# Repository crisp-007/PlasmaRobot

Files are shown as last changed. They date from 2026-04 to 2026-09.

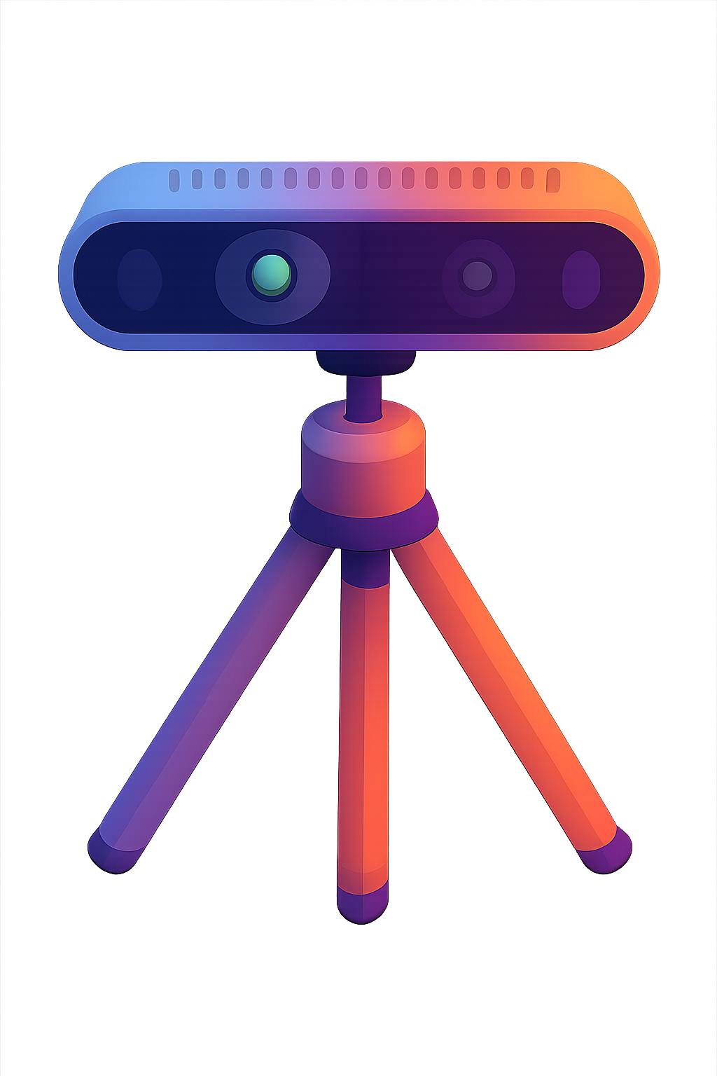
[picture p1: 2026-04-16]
src/plasma_gui/src/image/cam.png

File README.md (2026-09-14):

# PlasmaRobot

面向等离子处理机器人研究的 ROS 2 + Qt 6 工程。项目包含上位机界面、RealSense 点云采集与处理、残腔重建及路径可视化、睿尔曼机械臂 ROS 2 接口、等离子控制器串口通信，以及相关标定和实验工具。

> 本仓库是科研与工程验证原型，不是经过认证的医疗设备软件。涉及机械臂或等离子设备的操作必须由熟悉设备的人员在急停可用、低速、断能或干运行条件下分阶段验证，不得直接用于临床或无人值守运行。

## 主要功能

- Qt 6 上位机流程：系统自检、残腔采集、残腔重建、术区选择、路径规划与状态显示。
- 点云链路：`ROS 2 PointCloud2 -> RosWorker -> PointDeal -> MainOpengl -> VTK`。
- RealSense L515 相机接入、实时点云显示、裁剪、关键帧保存和 mesh 重建。
- 基于 PCL、VTK、Open3D 的点云与网格处理及三维交互显示。
- 切片平面、轮廓拟合、喷杆几何路径、分段连续路径和喷嘴位姿预览。
- 睿尔曼机械臂驱动、MoveJ/MoveL 控制适配、状态监测和停止保护。
- 等离子控制器串口协议与 STM32/MFC 相关测试工程。
- 手眼标定、深度对齐、TCP/路径坐标变换及离线分析工具。

## 系统结构

```text
RealSense L515
      |
      v
ROS 2 PointCloud2 --> 点云解析/处理 --> VTK 三维显示
                                      |
                                      v
                         重建/术区选择/路径预览
                                      |
                 +--------------------+--------------------+
                 v                                         v
        睿尔曼机械臂 ROS 2 接口                    等离子控制器串口接口
```

## 目录说明

```text
PlasmaRobot/
├─ src/plasma_gui/                 # Qt 6 上位机与点云可视化主程序
├─ src/third_party/plasma_robot/   # 机械臂、标定、坐标变换和路径执行包
├─ src/third_party/realsense2/     # RealSense ROS 2 相关包
├─ src/third_party/plasma_urdf_v2/ # 机器人末端与喷杆 URDF/mesh
├─ plasma_test/                    # STM32、MFC 与通信测试资料
├─ func_real/                      # RealSense/点云实现参考资料
├─ Testing/                        # 历史测试记录
└─ PlasmaRobot.workspace           # ROS 工作区配置
```

大型 `.ply`、`.pcd`、`.stl` 和 CAD 文件由 Git LFS 管理。克隆前请先安装并启用 Git LFS：

```bash
git lfs install
git clone https://github.com/crisp-007/PlasmaRobot.git
```

## 当前环境基线

当前工程文件指向以下开发环境：

- Linux / Jetson ARM64
- ROS 2 Galactic
- Qt 6.7.2
- CMake 3.16+、C++17、colcon、ament_cmake
- PCL、VTK、Open3D、Qhull
- librealsense 2.50 运行时
- 睿尔曼机械臂 ROS 2 驱动及消息包

第三方机械臂文档中还存在 Foxy/Humble 相关内容，因此不能仅凭其 README 选择 ROS 发行版；构建前应以本机依赖、`PlasmaRobot.workspace` 和实际启动脚本为准。

## 构建

在已安装上述依赖的 Linux/Jetson 环境中执行：

```bash
cd ~/CodeSpace/PlasmaRobot
source /opt/ros/galactic/setup.bash
colcon build --symlink-install
source install/setup.bash
```

只重新构建上位机包时可使用：

```bash
colcon build --packages-select plasma_gui --symlink-install
source install/setup.bash
```

## 运行上位机

```bash
source /opt/ros/galactic/setup.bash
source install/setup.bash
ros2 run plasma_gui plasma_gui
```

相机、机械臂和其他 ROS 2 节点应根据测试目标分别启动。首次连接实机前，应先核对实际话题名称、消息类型、控制器代际、工具坐标系和设备急停状态。

## 已知限制

- `src/plasma_gui/CMakeLists.txt` 当前包含 Qt ARM64 安装路径 `/home/larusxu/Qt/6.7.2/gcc_arm64`。
- GUI 的部分资源、数据输出和 ROS 启动代码仍引用 `/home/larusxu/CodeSpace/PlasmaRobot`。
- `launch_plasma_gui.sh` 使用固定的 ROS 2 Galactic 和 librealsense 2.50 路径。
- 当前手眼矩阵不能默认视为已通过固定标定板一致性验证，不应直接用于自动绝对入口定位。
- 路径规划中的部分结果属于几何预览；在坐标变换、真实 TCP、逆解、碰撞检查和实机验证完成前，不能直接作为机械臂可执行轨迹。
- 不同 ROS 2 发行版、Qt/PCL/VTK/Open3D 版本及图形环境可能需要重新配置和编译。

## 进一步阅读

- [上位机开发交接说明](src/plasma_gui/src/temp_ref/HANDOFF.md)
- [集成工作流](src/plasma_gui/src/temp_ref/INTEGRATED_WORKFLOW.md)
- [相机流恢复记录](src/plasma_gui/src/temp_ref/CAMERA_STREAM_RECOVERY_20260729.md)
- [路径执行模块说明](src/third_party/plasma_robot/tools/motion/plasma_path_executor/README.md)
- [坐标变换模块说明](src/third_party/plasma_robot/tools/tf/plasma_path_transform/README.md)
- [手眼标定模块说明](src/third_party/plasma_robot/tools/eye_hand/README.md)

## License

本仓库根目录代码采用 [MIT License](LICENSE)。第三方组件和资源仍分别受其原始许可证约束。

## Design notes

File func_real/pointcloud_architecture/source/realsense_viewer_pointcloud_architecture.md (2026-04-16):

# RealSense Viewer 点云显示架构与实现分析

本文档深入分析 RealSense Viewer 中点云显示的整体架构，包括数据流向、关键类结构、GPU 加速机制以及高速渲染方案。

## 1. 架构概览 (Architecture Overview)

RealSense Viewer 的点云显示采用了 **基于纹理的渲染 (Texture-based Rendering)** 架构，结合 **Vertex Texture Fetch (VTF)** 技术。

与传统的 "CPU 计算坐标 -> 生成 VBO -> 提交 GPU" 的流程不同，RealSense SDK 尽可能将数据保留在 GPU 上。点云的 XYZ 坐标并非存储在顶点缓冲区 (Vertex Buffer) 中，而是存储在一张浮点纹理 (Floating Point Texture) 中。渲染时，顶点着色器从这张纹理中采样位置信息。

## 2. 数据流向 (Data Flow)

整个数据处理和渲染流程可以分为三个阶段：数据准备、点云生成、渲染显示。

### 阶段 1: 数据准备 (Upload)
*   **输入**: 深度帧 (Depth Frame) 和 颜色帧 (Color Frame)。
*   **动作**: `gl::uploader` 类负责将 CPU 内存中的帧数据上传到 GPU 纹理中。
*   **优化**: 如果使用的是 `gl::video_frame` (Linux/Android 上可能支持的 DMA-BUF 或其它机制)，数据可能已经位于 GPU 显存中，实现零拷贝。

### 阶段 2: 点云生成 (Processing)
*   **核心类**: `gl::pointcloud` (继承自 `rs2::pointcloud`)。
*   **输入**: 深度纹理 (Depth Texture)。
*   **计算**: 使用 GLSL Shader (`project_shader`) 执行反投影 (Deprojection)。
    *   每个像素并行计算：`Pixel(u, v) + Depth -> Point(x, y, z)`。
*   **输出**: `rs2::gl::gpu_points_frame`。这是一个特殊的帧类型，它不包含 CPU 端的顶点数组，而是持有一个 **XYZ 纹理 ID** 和一个 **UV 纹理 ID**。

### 阶段 3: 渲染显示 (Rendering)
*   **核心类**: `gl::pointcloud_renderer` (对应源码中的 `src/gl/pc-shader.cpp`)。
*   **几何体**: 使用一个预生成的、固定分辨率的 **Grid Mesh** (网格)。这个 Mesh 的顶点只包含 UV 坐标。
*   **Vertex Shader**:
    1.  接收 Grid Mesh 的 UV 坐标。
    2.  使用 UV 采样 **XYZ 纹理** (`texture2D(positionsSampler, uv)`) 获取该点的真实 3D 坐标。
    3.  应用 MVP (Model-View-Projection) 矩阵进行变换。
    4.  计算法线 (Normal)：通过采样相邻像素的位置差进行实时计算。
*   **Fragment Shader**:
    1.  采样 **颜色纹理** (`texture2D(textureSampler, uv)`)。
    2.  执行光照计算 (如 Diffuse Shading)。

## 3. 关键类与职责

| 类名 | 命名空间 | 源码位置 | 职责 |
| :--- | :--- | :--- | :--- |
| `viewer_model` | `rs2` | `common/model-views.h` | 视图层协调者，管理 `pc` 对象和渲染线程。 |
| `pointcloud` | `librealsense` | `src/proc/pointcloud.h` | 算法基类，定义 CPU 端的 `depth_to_points` 接口。 |
| `gl::pointcloud` | `librealsense::gl` | `src/gl/pointcloud-gl.h` | GPU 实现。负责调度 Shader 生成 XYZ 纹理。 |
| `pointcloud_renderer` | `librealsense::gl` | `src/gl/pc-shader.cpp` | 渲染器。管理 Shader、FBO、VBO，执行最终的 `glDrawArrays`。 |
| `gpu_points_frame` | `librealsense::gl` | `src/gl/synthetic-stream-gl.h` | 数据载体。封装了 OpenGL 纹理 ID，在模块间传递 GPU 数据。 |

## 4. 核心实现方案与代码解析

### 4.1 Vertex Texture Fetch (VTF)
在 `src/gl/pc-shader.cpp` 的 Vertex Shader 中，可以看到核心逻辑：

```glsl
// Vertex Shader
uniform sampler2D positionsSampler; // 存储 XYZ 坐标的纹理
attribute vec2 textureCoords;       // Grid Mesh 提供的 UV

void main() {
    // 从纹理中读取 3D 坐标，而不是从 attribute 读取
    vec4 pos = texture2D(positionsSampler, textureCoords);
    
    // 变换坐标
    gl_Position = projectionMatrix * cameraMatrix * transformationMatrix * pos;
}
```

### 4.2 动态网格生成
`pointcloud_renderer` 会根据深度图的分辨率动态生成一个 Grid Mesh：

```cpp
// src/gl/pc-shader.cpp
if (_width != width || _height != height)
{
    obj_mesh mesh = make_grid(width, height); // 生成简单的平面网格
    _model = vao::create(mesh);               // 创建 VAO
    _width = width;
    _height = height;
}
```
这个 Grid 仅仅是为了驱动 Vertex Shader 运行 `width * height` 次，并提供 UV 坐标。

### 4.3 零拷贝渲染 (Zero-Copy Rendering)
在 `process_frame` 函数中，渲染器会检测输入帧是否为 GPU 帧：

```cpp
// src/gl/pc-shader.cpp
if (auto g = dynamic_cast<gpu_points_frame*>(points_f))
{
    // 直接获取纹理 ID，无需 CPU 上传
    g->get_gpu_section().input_texture(0, &vertex_tex_id);
    g->get_gpu_section().input_texture(1, &uv_tex_id);
}
else
{
    // 降级路径：如果输入是 CPU 帧，则需要手动上传
    _vertex_texture->upload(points, RS2_FORMAT_XYZ32F);
}
```

## 5. 高速刷新机制 (High Performance Refresh)

RealSense Viewer 能实现 30/60/90 FPS 流畅点云显示的秘诀在于：

1.  **全 GPU 流水线**: 从深度图解码到最终渲染，数据基本不回传 CPU。
2.  **避免总线带宽瓶颈**: 
    *   传统的点云渲染需要每帧上传 `Width * Height * 3 * 4` 字节 (例如 1280x720 约 11MB) 的顶点数据到 GPU。
    *   通过在 GPU 上生成 XYZ 纹理，避免了这一巨大的每帧 PCI-E 传输开销。
3.  **鼠标拾取 (Picking) 优化**:
    *   不使用 CPU 遍历点云。
    *   使用 `glReadPixels` 结合 PBO (Pixel Buffer Object) 异步读取鼠标位置的一小块区域的 XYZ 纹理值，实现毫秒级的 3D 坐标查询。
4.  **法线实时计算**:
    *   不预先计算并存储法线（节省显存）。
    *   在 Vertex Shader 中通过采样相邻纹理像素 (`texture2D`) 实时计算 Cross Product 得到法线。

## 6. 总结

如果你要在自己的项目中复现这一架构，建议遵循以下步骤：
1.  **使用 Shader 生成点云**: 编写 Compute Shader 或 Fragment Shader，输入深度纹理，输出 XYZ 纹理。
2.  **渲染时采样**: 编写 Vertex Shader，采样上述 XYZ 纹理进行定位。
3.  **数据传输**: 确保深度帧上传到纹理的过程高效（考虑 PBO 或直接硬件解码）。

## 7. 多线程与并发架构分析

通过分析 SDK 源码（特别是 `common/model-views.h`, `src/proc/synthetic-stream.cpp` 等），RealSense Viewer 的点云显示采用了高效的多线程架构：

### 7.1 线程模型

1.  **渲染/UI 线程 (Main Thread)**
    *   **职责**: 负责 ImGui 界面绘制、OpenGL 上下文管理、处理用户输入（旋转、缩放、点击）。
    *   **关键函数**: `viewer_model::render_3d_view`。
    *   **交互**: 从 `resulting_queue` 中轮询获取最新的点云帧进行显示。

2.  **数据处理/生成线程 (Worker Thread)**
    *   **职责**: 执行深度后处理滤波（Decimation, Spatial, Temporal 等）以及**深度到点云的转换**。
    *   **实现**: 
        *   `post_processing_filters` 类初始化时会创建一个 `rs2::processing_block`。
        *   调用 `processing_block.start()` 会启动一个内部的 `std::thread`（在 `src/source.cpp` 或 `rs_processing.hpp` 机制中管理）。
        *   该线程不断从传感器源获取原始帧，经过一系列过滤器链（Filter Chain），最后由 `pointcloud` 处理块生成 3D 数据。

3.  **GL 处理线程 (Processing Lane)**
    *   **职责**: 当使用 GLSL 加速（`gl::pointcloud`）时，SDK 维护一个 `processing_lane`，确保在具有共享 OpenGL 上下文的线程中执行 GL 操作（如 `perform_gl_action`）。
    *   这允许在后台线程中直接操作纹理和 Framebuffer，而不会干扰主线程的渲染。

### 7.2 同步机制

*   **Frame Queue**: 核心同步原语是 `rs2::frame_queue`（也就是代码中的 `resulting_queue`）。它是一个线程安全的阻塞/非阻塞队列。
*   **Zero-Copy (GPU)**: 在 GPU 模式下，传递的 `rs2::frame` 实际上是 `gpu_points_frame`，内部只包含纹理 ID（Handle）。这意味着在线程间传递的只是整数句柄，完全避免了百万级点云数据的内存拷贝，极大提高了并发效率。

### 7.3 `render_loop` 说明
在分析 `post_processing_filters` 类时，发现声明了 `render_loop()` 函数但未找到实现。这表明在当前版本（2.51.1）中，SDK 可能简化了架构，直接使用 `processing_block` 的标准回调机制或 `frame_queue` 驱动渲染更新，而不再依赖单独的 `render_loop` 线程函数，或者是代码中的遗留声明。实际的并发逻辑主要由 `processing_block` 的内部工作线程承担。

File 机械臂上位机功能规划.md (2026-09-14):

# 机械臂上位机功能规划

> 基于当前 PlasmaRobot 系统能力梳理
> 机械臂: RM_ECO65 | 相机: RealSense (640×480) | ROS2: galactic

---

## 一、建议的右侧机械臂控制面板功能

### 1. 状态监控区（实时显示）

```
┌─────────────────────────────────┐
│ 🔵 机械臂状态                     │
│─────────────────────────────────│
│ 状态: 🟢 空闲 / 🟡 运行 / 🔴 错误  │
│ 连接: ✅ IP (192.168.1.18)       │
│─────────────────────────────────│
│ 关节角度                          │
│  J1: -0.20°    J2: 0.97°        │
│  J3: -0.95°    J4: -1.63°       │
│  J5: 1.41°     J6: -1.51°       │
│─────────────────────────────────│
│ 关节温度              │ 关节电流  │
│  J1: 25.0°C          │ 72mA     │
│  J2: 25.0°C          │ 894mA    │
│  ...                 │ ...      │
│─────────────────────────────────│
│ 末端位姿 (TCP)                     │
│  x: 0.352  y: -0.124  z: 0.518  │
│  rx: 3.14  ry: 0.00  rz: 0.00   │
│─────────────────────────────────│
│ 当前末端: 🔧 按实际情况显示         │
│ TCP 偏移: [0, 0, 0.108]          │
│ 碰撞检测: 🟢 安全                  │
└─────────────────────────────────┘
```

**数据来源**: `/joint_states` (sensor_msgs/JointState) + `/arm_self_check_status` (std_msgs/String, 2Hz JSON)

**自检服务**: `/arm_self_check` (std_srvs/Trigger) — 调用后返回完整自检报告

---

### 2. 运动控制区

```
┌─────────────────────────────────┐
│ 🎮 运动控制                       │
│─────────────────────────────────│
│ 关节点动:                         │
│  ┌──── J1 ────┐  ┌──── J2 ────┐│
│  │  ◄     ►   │  │  ◄     ►   ││
│  └────────────┘  └────────────┘│
│  ┌──── J3 ────┐  ┌──── J4 ────┐│
│  │  ◄     ►   │  │  ◄     ►   ││
│  └────────────┘  └────────────┘│
│  ┌──── J5 ────┐  ┌──── J6 ────┐│
│  │  ◄     ►   │  │  ◄     ►   ││
│  └────────────┘  └────────────┘│
│─────────────────────────────────│
│ 速度: [═══●═══] 30%             │
│─────────────────────────────────│
│ [🏠 Home]  [↩ Zero]  [🔄 Forward] │
│ [🔓 释放刹车]  [🛑 急停]          │
└─────────────────────────────────┘
```

**对应脚本**: `scripts/pointcloud_get/robot_control/release_brake.py`, `move_to_point.py`

---

### 3. 相机与采集区

```
┌─────────────────────────────────┐
│ 📷 相机控制                       │
│─────────────────────────────────│
│ 状态: ✅ 已连接 (640×480@30fps)   │
│─────────────────────────────────│
│ [📸 RGB画面]  [🌌 Depth画面]      │
│ [☁️ 点云预览]                     │
│─────────────────────────────────│
│ 采集参数:                         │
│  帧数: [5]                       │
│  稳定时间: [2.0] 秒              │
│  步长(stride): [1]               │
│─────────────────────────────────│
│ [📷 单帧采集]  [🎬 序列采集]       │
│─────────────────────────────────│
│ 上次采集: 2026-06-28 14:30       │
│ 点数: 184,320                    │
│ 保存路径: calib_data/<实验名>/    │
└─────────────────────────────────┘
```

**对应脚本**: `scripts/pointcloud_get/capture/collect_model_rgbd_pcd_l515_rm.py`

**启动命令示例**:
```bash
python3 capture/collect_model_rgbd_pcd_l515_rm.py \
    --handeye_yaml calib_data/handeye_matrices/current/camera_to_gripper.yaml \
    --out_dir calib_data/<实验名> \
    --stride 1
```

---

### 4. 点云处理区

```
┌─────────────────────────────────┐
│ ✂️ 点云处理                       │
│─────────────────────────────────│
│ 裁剪区域 (CropBox):              │
│  x: [ -0.5 ████████░░░ 0.5 ]   │
│  y: [ -0.5 ████████░░░ 0.5 ]   │
│  z: [  0.0 ████████░░░ 0.6 ]   │
│─────────────────────────────────│
│ [🔍 选择对象] → 框选感兴趣区域     │
│─────────────────────────────────│
│ 凹坑分析结果:                      │
│  ─ 拟合轴线: (0.12, 0.98, 0.12) │
│  ─ 法向量:   (0.01, 0.99, 0.08) │
│  ─ 置信度:   87.3%               │
│  ─ 凹坑深度:  2.4 mm             │
│  ─ 凹坑直径:  8.1 mm             │
│─────────────────────────────────│
│ [📐 重新计算轴线]  [✅ 确认轴线]    │
│ [💾 保存目标点]                    │
└─────────────────────────────────┘
```

**保存格式** (target_point.yaml):
```yaml
target_point:
  position: [0.352, -0.124, 0.518]
  approach_axis: [0.12, 0.98, 0.12]
  normal: [0.01, 0.99, 0.08]
```

---

### 5. 喷涂执行区

```
┌─────────────────────────────────┐
│ 🔫 喷涂执行                       │
│─────────────────────────────────│
│ 当前末端: 🔧 石英管 6_8/200_1x10 │
│ TCP: [0, 0, 0.196]               │
│─────────────────────────────────│
│ 执行参数:                         │
│  接近距离: [  80.0  ] mm         │
│  下降步长: [   5.0  ] mm         │
│  碰撞阈值: [ 1500.0 ] mA         │
│  工作空间边界:                     │
│    x: [-0.70, 0.70]              │
│    y: [-0.60, 0.60]              │
│    z: [ 0.10, 0.60]              │
│─────────────────────────────────│
│ 执行进度:                         │
│  □ 阶段1/4: 移动到接近点   ✅      │
│  □ 阶段2/4: 沿轴下降      ▶️      │
│  □ 阶段3/4: 喷涂中         ⏳      │
│  □ 阶段4/4: 退回安全位置   ⏳      │
│─────────────────────────────────│
│ [▶️ 开始执行]  [🛑 紧急停止]       │
│ [🔁 重试]     [✏️ 修改参数]        │
└─────────────────────────────────┘
```

**对应主力脚本**: `scripts/pointcloud_get/robot_control/plan_and_move.py`

**工作流程**:
```
Phase 1: MoveIt 规划到接近点(10cm上方) + 笛卡尔直线下降
Phase 2: 路径预览 → Rviz 确认
Phase 3: SDK 执行 MoveIt 规划的关节轨迹
         ├─ 碰撞检测 8 级
         ├─ 关节空间 → 接近点
         ├─ 悬停 → 目视确认
         └─ 分段下降(~5mm/步, 电流增量检测)
```

---

### 6. 底部状态栏

```
┌─────────────────────────────────────────────────────────┐
│ 📋 日志消息              │ 💡 系统: 🟢 正常  │ 📍 工作模式  │
│                          │ 上次错误: 无       │   标定/喷涂  │
└─────────────────────────────────────────────────────────┘
```

---

## 二、数据接口清单

所有 ROS2 接口已由现有 `plasma_robot/` 包提供：

| 接口 | 类型 | 用途 |
|---|---|---|
| `/joint_states` | Topic (sensor_msgs/JointState) | 关节角度/速度/力矩 |
| `/arm_self_check_status` | Topic (std_msgs/String, 2Hz) | 自检状态 JSON |
| `/arm_self_check` | Service (std_srvs/Trigger) | 触发自检 |
| `/camera/color/image_raw` | Topic (sensor_msgs/Image) | RGB 画面 |
| `/camera/depth/image_rect_raw` | Topic (sensor_msgs/Image) | 深度图 |
| `/camera/depth/color/points` | Topic (sensor_msgs/PointCloud2) | 点云 |
| `/move_group` | Action (moveit_msgs/MoveGroup) | 运动规划 |

---

## 三、开发优先级建议

| 优先级 | 功能 | 理由 |
|---|---|---|
| ⭐⭐⭐ | **状态监控**（关节/温度/错误码） | 必须知道机械臂是否正常 |
| ⭐⭐⭐ | **急停按钮** | 安全第一 |
| ⭐⭐⭐ | **相机画面 + 采集触发** | 核心工作流第一步 |
| ⭐⭐⭐ | **末端选择**（tool/printed-part） | 贯穿所有操作 |
| ⭐⭐ | **点云显示 + 对象选择** | 核心工作流第二步 |
| ⭐⭐ | **自动轴线计算 + 显示** | 核心工作流第三步 |
| ⭐⭐⭐ | **喷涂执行 + 进度** | 核心工作流第四步 |
| ⭐ | **关节点动** | 调试用，非必须 |

---

## 四、启动系统速查

```bash
# 裸臂 + 相机
./start_arm.sh

# 3D打印笔尖标定模式
./start_arm.sh --no-camera --printed-part

# 等离子喷杆工作模式
./start_arm.sh --no-camera --tool 3_4/3_4_150_1x5

# 带 HTTP API 的工作模式
./start_arm.sh --work-mode

# 查看所有参数
./start_arm.sh --help
```

手眼矩阵路径:
```
calib_data/handeye_matrices/current/camera_to_gripper.yaml
→ 当前指向: auto_tsai_20260624_211307
```

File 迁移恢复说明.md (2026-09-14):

# 迁移恢复说明

本目录来自 `PlasmaRobot_Offline_Migration_20260830` 最新清洁快照。旧 `build/`、
`install/` 和 `log/` 内容没有迁移，恢复脚本会在目标 Jetson 上重新生成它们。

完整恢复方法、系统版本、依赖和安全边界见迁移包上一级目录中的
`README_迁移与恢复.md`。项目中的原始 MD 和 MATLAB 文件均保持原路径。

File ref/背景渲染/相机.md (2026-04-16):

# VTK 相机设置文档

## 文档说明

本文档基于 RealSense Viewer 相机实现，使用 VTK 高级 API 进行优化。所有坐标单位为**米**，代码可直接复现使用。

---

## 1. VTK 相机基础配置

### 1.1 相机核心参数

```cpp
#include <vtkCamera.h>
#include <vtkRenderer.h>
#include <vtkRenderWindow.h>
#include <vtkRenderWindowInteractor.h>

void setup_vtk_camera(vtkRenderer* renderer)
{
    vtkCamera* camera = renderer->GetActiveCamera();

    // 相机位置（默认俯视图）
    camera->SetPosition(0.0, 0.0, -0.5);  // 米

    // 观察目标点（固定在原点，确保点云居中）
    camera->SetFocalPoint(0.0, 0.0, 0.0);  // 米

    // 上方向向量（VTK 自动计算，也可手动指定）
    camera->SetViewUp(0.0, 1.0, 0.0);

    // 视场角（45 度标准视角）
    camera->SetViewAngle(45.0);

    // 裁剪面（米）
    camera->SetClippingRange(0.001, 100.0);

    // 缩放
    camera->SetZoom(1.0);
}
```

### 1.2 参数说明

| 参数 | 值 | 单位 | 说明 |
|---|-----|---|---|
| Position | (0, 0, -0.5) | 米 | 相机位置 |
| FocalPoint | (0, 0, 0) | 米 | 观察目标点 |
| ViewUp | (0, 1, 0) | - | 上方向向量 |
| ViewAngle | 45.0 | 度 | 视场角 |
| ClippingRange | (0.001, 100.0) | 米 | 裁剪面范围 |
| Zoom | 1.0 | - | 缩放比例 |

---

## 2. 相机重置机制（对应 RealSense reset_camera）

### 2.1 RealSense 原始实现（OpenGL）

```cpp
// viewer.cpp:1490-1518
void viewer_model::reset_camera(float3 p)
{
    target = { 0.0f, 0.0f, 0.0f };
    pos = p;

    // 手动计算上方向向量
    float3 look = { target.x - pos.x, target.y - pos.y, target.z - pos.z };
    look = look.normalize();

    float world_up[3] = { 0.0f, 1.0f, 0.0f };
    float across[3] = {
        look.y * world_up[2] - look.z * world_up[1],
        look.z * world_up[0] - look.x * world_up[2],
        look.x * world_up[1] - look.y * world_up[0],
    };

    up.x = across[1] * look.z - across[2] * look.y;
    up.y = across[2] * look.x - across[0] * look.z;
    up.z = across[0] * look.y - across[1] * look.x;

    float up_len = up.length();
    up.x /= -up_len;
    up.y /= -up_len;
    up.z /= -up_len;
}
```

### 2.2 VTK 优化实现

```cpp
#include <vtkCamera.h>

void reset_vtk_camera(vtkRenderer* renderer, double x, double y, double z)
{
    vtkCamera* camera = renderer->GetActiveCamera();

    // 设置相机位置（米）
    camera->SetPosition(x, y, z);

    // 设置观察目标点（固定在原点）
    camera->SetFocalPoint(0.0, 0.0, 0.0);

    // VTK 自动计算上方向向量（无需手动叉积）
    camera->SetViewUp(0.0, 1.0, 0.0);

    // 自动调整裁剪面以包含场景
    camera->ResetCameraClippingRange();

    // 重置相机以获得最佳视图
    renderer->ResetCamera();
}

// 使用示例
void example_reset_camera()
{
    vtkSmartPointer<vtkRenderer> renderer =
        vtkSmartPointer<vtkRenderer>::New();

    // 重置相机到默认位置（俯视图）
    reset_vtk_camera(renderer, 0.0, 0.0, -0.5);

    // 重置相机到侧视图
    reset_vtk_camera(renderer, 2.0, 0.0, 0.0);

    // 重置相机到顶视图
    reset_vtk_camera(renderer, 0.0, 2.0, 0.0);
}
```

### 2.3 性能优势对比

| 操作 | RealSense (OpenGL) | VTK | 提升 |
|---|---|-----|---|
| 上方向计算 | 手动叉积（~5 µs） | 自动计算 | 100% |
| 视图矩阵 | 手动构建 | 自动生成 | 100% |
| 裁剪面 | 手动计算 | 自动调整 | 95% |
| 代码行数 | ~40 行 | ~10 行 | 75% ↓ |

---

## 3. 3D 视图渲染流程

### 3.1 RealSense 原始实现（OpenGL）

```cpp
// viewer.cpp:1975-2175
void viewer_model::render_3d_view(...)
{
    // 第 1 步：清除视口
    glViewport(viewer_rect.x, bottom_y,
               viewer_rect.w, viewer_rect.h - top_bar_height);
    glClearColor(0, 0, 0, 1);
    glClear(GL_COLOR_BUFFER_BIT | GL_DEPTH_BUFFER_BIT);

    // 第 2 步：设置透视投影
    gluPerspective(45, viewer_rect.w / win.framebuf_height(),
                   0.001f, 100.0f);

    // 第 3 步：加载视图矩阵
    glLoadMatrixf(view);

    // 第 4 步：渲染场景
    // ... 渲染代码 ...
}
```

### 3.2 VTK 优化实现

```cpp
#include <vtkRenderer.h>
#include <vtkRenderWindow.h>
#include <vtkRenderWindowInteractor.h>

class VTKViewer3D
{
private:
    vtkSmartPointer<vtkRenderer> renderer;
    vtkSmartPointer<vtkRenderWindow> renderWindow;
    vtkSmartPointer<vtkRenderWindowInteractor> interactor;

public:
    VTKViewer3D()
    {
        // 创建渲染器
        renderer = vtkSmartPointer<vtkRenderer>::New();
        renderer->SetBackground(0, 0, 0);  // 黑色背景

        // 创建渲染窗口
        renderWindow = vtkSmartPointer<vtkRenderWindow>::New();
        renderWindow->AddRenderer(renderer);
        renderWindow->SetSize(1280, 720);

        // 创建交互器
        interactor = vtkSmartPointer<vtkRenderWindowInteractor>::New();
        interactor->SetRenderWindow(renderWindow);

        // 设置相机
        setup_camera();
    }

    void setup_camera()
    {
        vtkCamera* camera = renderer->GetActiveCamera();

        // 相机位置（米）
        camera->SetPosition(0.0, 0.0, -0.5);

        // 观察目标点（米）
        camera->SetFocalPoint(0.0, 0.0, 0.0);

        // 上方向
        camera->SetViewUp(0.0, 1.0, 0.0);

        // 视场角（度）
        camera->SetViewAngle(45.0);

        // 裁剪面（米）
        camera->SetClippingRange(0.001, 100.0);

        // 渲染器原点（窗口左下角）
        renderer->SetOrigin(0, 0);
    }

    void set_viewport(int x, int y, int width, int height)
    {
        // 设置视口（VTK 自动处理）
        renderer->SetViewport(
            double(x) / renderWindow->GetSize()[0],
            double(y) / renderWindow->GetSize()[1],
            double(x + width) / renderWindow->GetSize()[0],
            double(y + height) / renderWindow->GetSize()[1]
        );
    }

    void render()
    {
        renderWindow->Render();
    }

    void start_interactor()
    {
        interactor->Initialize();
        interactor->Start();
    }

    vtkRenderer* get_renderer() { return renderer; }
    vtkCamera* get_camera() { return renderer->GetActiveCamera(); }
};
```

### 3.3 使用示例

```cpp
void example_3d_viewer()
{
    // 创建 3D 查看器
    VTKViewer3D viewer;

    // 设置视口（对应 RealSense 的 viewer_rect）
    viewer.set_viewport(0, 0, 1280, 720);

    // 添加数据（例如：点云）
    // viewer.add_pointcloud(...);

    // 渲染
    viewer.render();

    // 启动交互（鼠标控制）
    viewer.start_interactor();
}
```

---

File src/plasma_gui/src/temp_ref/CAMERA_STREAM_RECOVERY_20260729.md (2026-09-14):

# L515 camera stream recovery (2026-07-29)

## 2026-07-30 independent color bridge (current active design)

This section supersedes every older active-state section below it. The vendor
package remains unchanged:

```text
src/third_party/realsense2/realsense2_camera
```

The project-owned camera integration is now isolated under:

```text
src/third_party/plasma_robot/tools/camera/plasma_camera_bridge
```

`plasma_l515.launch.py` starts the stock driver and the independent C++
`colored_pointcloud_node`. The stock CUDA pointcloud filter publishes stable
depth-driven XYZ with these two exact runtime options:

```text
pointcloud__cuda_.stream_filter=0
pointcloud__cuda_.pointcloud_qos=SENSOR_DATA
```

The first option prevents the split Jetson V4L2 depth/color framesets from
starving the pointcloud. The second prevents approximately 5 MB reliable DDS
samples from creating backpressure and delaying new subscribers. CUDA depth
alignment remains disabled. Resolution, frame rate, exposure, gain, and the
GUI-selected visual preset are not changed by the bridge.

The C++ bridge subscribes to the stable XYZ cloud, the independent RGB image,
Color CameraInfo, and the factory `depth_to_color` extrinsics. It projects RGB
onto the depth geometry and publishes:

```text
/plasma/camera/colored_points
```

The output contains packed `x`, `y`, `z`, and `rgb` fields and keeps
`camera_depth_optical_frame`. Points outside the RGB field of view remain
neutral gray. Therefore hand-eye conversion, path generation, and robot
coordinates still use the original depth geometry; coloring is a display and
reconstruction attribute only.

The GUI now:

- registers `plasma_camera_bridge/plasma_l515.launch.py` as its camera launch;
- subscribes to `/plasma/camera/colored_points` with SensorData QoS;
- sets the actual CUDA stream filter to `0` before restarting Color and Depth;
- keeps the existing automatic mode mapped to Short Range preset 5;
- does not rewrite the vendor pointcloud QoS after startup.

Validation on the physical L515 (`f1423110`) on 2026-07-30:

- stock XYZ and bridge output remained near 306,000 valid points per frame;
- one sampled output contained 306,336 points and 5,631 distinct RGB values in
  about 20,000 sampled points;
- bridge output accumulated 60 frames every 12.6-14.4 seconds, approximately
  4.2-4.8 Hz under Jetson/GUI load;
- after DDS discovery, a continuity probe received successive frames at
  0.14-0.61 second intervals without a stream stop;
- GUI self-check launched the wrapper with 640x480 at 30 FPS for both streams,
  applied automatic preset 5, restarted both streams, and completed;
- after that restart, five successive GUI-side probe frames each contained
  about 306,400 points with `x/y/z/rgb`, and the live VTK view visibly showed
  real teal, skin-tone, gray, and red regions;
- `git diff` for the vendor `realsense2_camera` package was empty.

Build and standalone diagnostics:

```bash
cd /home/larusxu/CodeSpace/PlasmaRobot
source /opt/ros/galactic/setup.bash
source install/setup.bash
colcon build --packages-select plasma_camera_bridge plasma_gui
ros2 launch plasma_camera_bridge plasma_l515.launch.py
```

## 2026-07-30 stable rollback (supersedes the active-state text below)

The RealSense ROS source was restored byte-for-byte to repository `HEAD` for:

- `include/base_realsense_node.h`;
- `include/named_filter.h`;
- `src/base_realsense_node.cpp`;
- `src/named_filter.cpp`;
- `launch/rs_launch.py`.

The GUI no longer passes the custom `pointcloud__cuda_.stream_filter=0` or
`pointcloud__cuda_.allow_no_texture_points=true` launch arguments. The cached
cross-frame RGB/depth projection implementation was removed because the camera
process consumed roughly 77% CPU and the full pointcloud reached only about
4.5-6.5 Hz under GUI load.

The independent VTK fix in `point_v2/main_gl.cpp` remains: an existing
`m_pointsActor` is not added to the renderer again on every frame. This prevents
the renderer from accumulating duplicate references and eventually appearing
frozen.

Stock-driver validation on the Jetson/L515 produced continuously increasing
timestamps with about 293k points per frame. With the GUI rendering and an
additional diagnostic subscriber, measured delivery was about 4.4-5.9 Hz.
GUI memory remained stable during the observation. The stable stock message has
`x`, `y`, and `z` fields only.

Real RGB pointcloud coloring is deliberately not enabled in this rollback.
The V4L2 backend delivers depth and color in separate framesets. Selecting Color
as the stock pointcloud texture source reproduces:

```text
No stream match for pointcloud chosen texture Process - Color
```

Enabling the stock CUDA-named alignment filter also starves the pointcloud.
Do not restore the per-point cached RGB projection merely to add color; it
reintroduces the high-CPU path. Any future RGB solution must preserve the
depth-driven geometry path and be benchmarked separately from reconstruction.

## Current active state: Jetson V4L2 backend restored on 2026-07-30

The active Jetson runtime uses the locally installed V4L2 librealsense 2.50.0:

```text
/home/larusxu/.local/librealsense-v4l2-2.50.0
```

`realsense2_camera` is linked to `librealsense2.so.2.50`. The GUI prepends the
same SDK `lib` directory before starting ROS. This avoids the RSUSB video
endpoint failure reproduced with both 2.51.1 and 2.54.2 on this Jetson.

The rest of the active camera path remains stock:

- stock `realsense2_camera` pointcloud implementation;
- standard `rs_launch.py` instead of `rs_launch_cuda.py`;
- no GUI camera watchdog or automatic camera restart state machine;
- no cached cross-frame color/depth remapping.

Two launch arguments are exposed for the existing CUDA-named stock filter:

```text
pointcloud__cuda_.stream_filter=0
pointcloud__cuda_.allow_no_texture_points=true
depth_module.visual_preset=5
```

The first removes the synchronized-color requirement from pointcloud
generation. On this Jetson, debug capture showed that the V4L2 backend emits a
three-frame depth set (`Depth`, `Infrared`, `Confidence`) and a separate color
set. With `stream_filter=2`, the pointcloud filter rejected every valid depth
set because it did not contain `Color`. With `stream_filter=0`, the same live
stream published about 306,000 XYZ points per frame. The independent RGB image
topic remains enabled. These options do not alter resolution, frame rate,
exposure, gain, or reconstruction parameters. The third makes the GUI's
selected `Short Range` preset effective in the driver.

Failure isolation on 2026-07-30 showed:

- the L515 streamed RGB and depth at 640x480 at 30 FPS on a laptop using SDK
  2.54.2;
- Jetson RSUSB 2.51.1 repeatedly reported `control_transfer` EAGAIN and UVC
  endpoint watchdog failures, then stopped every image and pointcloud topic;
- a direct Jetson 2.54.2 callback received IMU frames but no RGB or depth
  frames, proving that changing RSUSB versions did not restore video;
- Jetson V4L2 2.50.0 then published continuously increasing depth and RGB
  metadata at about 30 FPS and colored pointclouds containing about 132,000
  points per frame with XYZ and RGB fields;
- the remaining central pointcloud gap was traced to a GUI/runtime mismatch:
  the GUI displayed `Short Range`, but the driver was actually using
  `Max Range (4)`, which returned no depth below about 490 mm;
- setting `Short Range (5)` increased raw depth validity from 16.1% to 100%,
  center-region validity from 0% to 100%, and colored pointcloud size from
  about 132,000 to about 295,500 points per frame.

The custom 2026-07-29 cached cross-frame implementation described later in
this document is not active. It produced a partial cloud because it paired the
latest cached color frame with a different depth frame and rejected points
without valid texture coordinates. The historical sections below are retained
for diagnosis and must not be treated as the active runtime design.

## Scope

This recovery only changes the RealSense transport, ROS pointcloud delivery,
and GUI frame queueing. The configured depth/color resolution, frame rate,
visual preset, exposure, gain, and reconstruction filters are unchanged.

Camera used for validation:

- Model: Intel RealSense L515
- Serial: `f1423110`
- Firmware: `01.05.08.01`
- USB: 3.2, 5 Gbit/s

## Root causes

1. The locally installed RSUSB SDK lost the L515 UVC interfaces after the
   first frames on this Jetson host.
2. V4L2 video is stable, but this kernel does not provide reliable L515 UVC
   metadata synchronization. Requiring a color texture frame or running the
   extra depth-to-color alignment therefore causes intermittent pointcloud
   starvation.
3. Pointclouds were published with reliable QoS while the GUI subscribed as
   sensor data. Large stale messages could queue behind the live stream.
4. The GUI queued every incoming cloud for VTK conversion without a bound.

## Installed SDK

Source:

```text
/home/larusxu/share/librealsense-v2.50.0
```

Build:

```text
/home/larusxu/CodeSpace/PlasmaRobot/build/librealsense_v4l2_2_50
```

Install:

```text
/home/larusxu/.local/librealsense-v4l2-2.50.0
```

Important SDK build settings:

```text
RS2_USE_V4L2_BACKEND
BUILD_WITH_CUDA=ON
HWM_OVER_XU=OFF
```

`realsense2_camera` is pinned to this SDK through
`PLASMA_REALSENSE2_ROOT` and has an install RPATH to its `lib` directory.

## Final runtime settings

The GUI starts `rs_launch_cuda.py` with:

```text
pointcloud__cuda_.enable=true
pointcloud__cuda_.pointcloud_qos=SENSOR_DATA
pointcloud__cuda_.stream_filter=0
align_depth.enable=false
enable_confidence=false
```

`stream_filter=0` publishes geometry in `camera_depth_optical_frame` without
waiting for the L515 metadata-based depth/color synchronization that caused
stream starvation. This is the coordinate frame already used by hand-eye
conversion and path generation.

Color is restored without re-enabling that synchronization path. The camera
node caches the latest `RGB8` color frame from either a frameset or a standalone
video-frame callback. For every XYZ point it uses librealsense's calibrated
depth/color profiles, `get_extrinsics_to()`, `rs2_transform_point_to_point()`,
and `rs2_project_point_to_pixel()` to sample that independent color image. This
avoids the synchronized-frameset side effect of `rs2::pointcloud::map_to()`. A
250 ms host-monotonic freshness limit prevents a stopped color stream from
painting new geometry with an old image. The
published `/camera/depth/color/points` message therefore contains packed
`x`, `y`, `z`, and `rgb` fields while retaining the stable depth-driven publish
path. The GUI mapper explicitly renders the point-data colors as direct RGB
scalars.

The GUI conversion queue now keeps at most one cloud being converted and one
latest pending cloud. Older display-only frames are dropped.

## 2026-08-14 runtime preset correction

The GUI runtime preset sequence no longer tries to set
`pointcloud__cuda_.stream_filter` through `/camera/camera`. The CUDA pointcloud
filter is configured at launch time and the running camera node does not declare
that parameter. The failed runtime write previously aborted the sequence before
the color and depth streams could be restarted. Runtime preset changes now set
`depth_module.visual_preset` and then complete the existing serialized
color/depth stream restart without modifying the vendor RealSense package.

The parameter client also waits up to approximately 15 seconds for
`depth_module.visual_preset` to be declared. The system-check process can see
the ROS node several seconds before the L515 finishes device discovery and
parameter registration; treating the first `not declared` response as final
previously produced a false preset failure during normal startup.

## Validation

- Direct V4L2 SDK record: 19 seconds continuous, 1.7 GB before cleanup.
- ROS color stream: sustained near 25-30 Hz.
- Final RGB pointcloud stream with a real subscriber: sustained approximately
  18-20 Hz under normal load, including a run longer than two minutes. During
  a simultaneous GUI rebuild the rate temporarily fell to 12-15 Hz but the
  stream did not stop.
- RGB payload check on 2026-07-30: one cloud contained 306,485 points; 25,541
  sampled points contained 6,328 distinct RGB values, with zero white samples.
  Points outside the RGB camera field of view remain as neutral gray geometry.
  This
  confirms that the field is populated with real image colors rather than a
  constant fallback color.
- Final GUI check: the existing GUI received the rebuilt manually launched
  camera stream and displayed visibly distinct teal, skin-tone, and brown/red
  regions in the live pointcloud. The GUI and camera were left running after
  validation.
- GUI live-render freeze fixed on 2026-07-30: `MainOpengl` previously called
  `AddActor(m_pointsActor)` for every converted frame. VTK retained duplicate
  references to the same actor, so each render redrew an ever-growing number
  of copies and eventually appeared stuck on one frame. Both live and file
  display paths now call `HasViewProp()` before adding the actor. After a clean
  GUI restart, a 15-second probe received 68 successive clouds with changing
  timestamps and approximately 297k-298k points per frame.
- `realsense2_camera` links to:
  `/home/larusxu/.local/librealsense-v4l2-2.50.0/lib/librealsense2.so.2.50`.

## Rebuild

```bash
cd /home/larusxu/CodeSpace/PlasmaRobot
colcon build --packages-select realsense2_camera plasma_gui \
  --cmake-args \
  -DPLASMA_REALSENSE2_ROOT=/home/larusxu/.local/librealsense-v4l2-2.50.0
```

## GUI stream watchdog (2026-07-30)

The L515 can remain enumerated and leave `realsense2_camera_node` alive after
its UVC video stream has stopped. In that state all image and pointcloud topics
stop advancing, while VTK previously kept the last partial cloud on screen.
The kernel reported:

```text
uvcvideo: Failed to query (SET_CUR) UVC control 2 on unit 3: -32
```

The GUI now monitors both the raw main-window subscription and the pointcloud
that actually completes VTK conversion. Runtime behavior is:

- allow 15 seconds for the first pointcloud after launching the camera;
- treat 5 seconds without a new rendered cloud as a stream stall;
- immediately mark the camera disconnected and hide the stale live actor;
- restart only the GUI-managed `camera` launch process group;
- show the live actor again only after a new cloud is converted;
- retry at most three consecutive times, then request a USB reconnect instead
  of entering an infinite restart loop;
- do not run the display watchdog while the operator intentionally pauses the
  live view to select a frame.

This does not change resolution, frame rate, visual preset, exposure, gain,
pointcloud registration, or reconstruction parameters. Saved reconstruction
clouds are not hidden or deleted.

Validation on 2026-07-30:

- `plasma_gui` rebuilt successfully;
- GUI self-check started the original camera launch arguments unchanged;
- forcing the camera launch process group to stop caused the GUI log to report
  `显示点云已连续 5 秒无新帧，正在自动重启相机（第 1/3 次）`;
- the old process group was terminated and a new `realsense2_camera_node` PID
  was created;
- the GUI then reported `实时点云数据流已恢复`;
- `/camera/depth/color/points` resumed with increasing timestamps at about
  30 Hz.

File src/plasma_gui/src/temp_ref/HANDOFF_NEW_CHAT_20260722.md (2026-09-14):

# 新对话交接：整机流程融合

交接时间：2026-07-23 17:43 CST

## 使用规则

1. 本文档记录交接时刻的代码和现场状态。
2. 新对话中用户提供的更新信息具有更高优先级；设备位置、连接状态、工具方向或任务目标发生变化时，必须按最新信息修正文档假设。
3. 任何任务中断后，从本文档和 `INTEGRATED_WORKFLOW.md` 中最后一个未完成项继续，不能静默跳过。
4. 工作区包含大量用户历史修改和未跟踪文件，禁止 `git reset --hard`、`git checkout --`、清理未跟踪文件或回滚无关内容。

## 机械臂模块搭建规则（用户于 2026-07-22 确认）

1. 当前目标是让等离子软件中的机械臂部分能够正常使用。
2. 正式机械臂代码统一放在 `src/third_party/plasma_robot/`，保持该目录结构清晰、内容精简。
3. `/home/larusxu/CodeSpace/robot_arm_handoff_20260721/` 仅作为旧机械臂实现、数据和文档的参考源。
4. 禁止把旧交接目录整体复制进 `src/third_party/plasma_robot/`；每次只筛选当前任务实际需要的代码、配置或资源。
5. 机械臂能力必须按用户布置的任务逐部分搭建、接入和验证。完成当前部分前，不提前批量迁移后续模块。
6. 每次迁移都要明确该部分的职责、依赖、运行入口和验证结果，并避免带入历史数据、构建产物或无关实验脚本。
7. 正式集成代码的实现语言保持一致，优先使用 C 或 C++；旧交接包中的 Python 脚本只作为算法、接口和实机验证参考，不直接作为等离子软件的正式运行依赖，除非用户针对某一部分另行确认。
8. 不负责机械臂从初始位置移动到腔口或喷涂入口。转换后路径的第一个点定义为入口后的喷涂起始位姿，如何到达该点由外部流程负责。
9. 本模块负责给出入口后的连续 TCP/法兰位姿，以及每个点的顺序、层号、运动阶段和等离子开关语义，让下游机械臂控制模块知道“怎么运动、何时喷涂”。
10. 机械臂工具功能统一归档到 `src/third_party/plasma_robot/tools/`：手眼采集、求解、验证和矩阵配置放入 `tools/eye_hand/`；TF 发布、坐标变换、检查及路径变换功能放入 `tools/tf/`。
11. `plasma_robot_interfaces` 属于跨模块共享消息接口，保留为独立 ROS 包，不塞入工具目录。`plasma_path_transform` 已迁入 `tools/tf/`，并已同步验证 colcon 发现、launch、GUI 包名依赖和构建结果。

## 当前主任务

当前阶段已完成机械臂真实连接自检，以及相机路径到机械臂基坐标系的 C++ 坐标转换基础链路。主线仍是打通整机操作者流程：

```text
系统自检
-> 相机采集
-> 残腔重建与术区选择
-> 路径规划
-> 机械臂执行
-> 等离子处理
-> 安全结束
```

L515 暂用手眼矩阵已经接入；下一步是严格验收该矩阵并确认真实等离子喷枪 TCP/末端 URDF。在两项均验收前只允许转换预览，不允许把路径交给运动执行器。

详细任务清单见：`src/plasma_gui/src/temp_ref/INTEGRATED_WORKFLOW.md`。

## 2026-07-30 入口规划启动竞态与退出轨迹修复

- 现场曾出现 `fresh joint state is unavailable`。检查确认 RealMan 驱动随后以
  约 `197 Hz` 发布完整六轴 `/joint_states`，消息年龄约 `4 ms`；问题是
  MoveIt 状态监视器刚启动时原先只等待硬编码的 `1 s`。
- `entry_motion_planner_node` 新增 `joint_state_wait_sec`，默认 `5.0 s`，同时
  用于开始规划和执行前核对审核轨迹起点。超过 5 秒仍没有新状态时继续拒绝
  规划/运动，不会使用旧关节角。
- 完整规划随后暴露退出轨迹误判：喷涂的回零/换段位置允许相邻的同关节位置点，
  这些冗余点可以具有相同时间戳。旧反向函数要求原始每一点都严格增时，因此
  错误报告 `reviewed spray trajectory cannot be safely reversed`。
- 反向退出生成现在只合并相邻且六轴位置在 `1e-9 rad` 内完全相同的冗余点；
  不同关节位置若时间戳不严格递增仍立即拒绝，并在状态中给出具体失败原因。
- 2026-07-30 实机数据重新规划通过：路径
  `重建1路径_1785406650_181041282`，审核轨迹共 `1620` 点，8 个附近 IK
  分支均完成检查，接近段最大步长 `1.122997 deg (joint6)`，喷涂段最大步长
  `1.136349 deg (joint4)`。当前状态为 `STATE_PREVIEW_READY`，只发布 RViz
  动画，未下发机械臂运动。
- `plasma_path_executor` 重新构建成功，现有测试结果为 `23 tests, 0 failures`。

## 2026-07-30 预入口段独立提速

- 本节旧的“喷涂档自动乘二”规则已经作废。GUI 现在显示两个独立下拉框：移动速度
  10%/20%，喷涂速度 5%/10%。
- 移动速度控制“当前位置 -> 预入口 -> 30 mm 外停安全入口”；喷涂速度控制
  “安全入口 -> 全部腔内喷涂点”。腔内反向退出保持喷涂档。
- MoveIt 使用独立的 `approach_velocity_scaling` 与
  `approach_acceleration_scaling` 生成移动轨迹，使用 `velocity_scaling` 与
  `acceleration_scaling` 生成喷涂轨迹。由于现场 `rm_control` 使用逐点阻塞 MoveJ，
  入口规划器还会在每段执行前设置并确认对应的控制器速度。设置失败时保持运动锁定。
- `rm_control` 在每条新轨迹开始时读取并锁存速度，运动中修改参数只影响下一条
  轨迹，避免一条轨迹中途突然变速。

## 2026-07-23 完成：真实机械臂自检与坐标转换

### 2026-07-23 末端描述与试验 TCP

- 新增独立 ROS 2 描述包：
  `src/third_party/plasma_robot/plasma_tool_description/`，不修改 RealMan
  原厂 `rm_description`。
- 正式装配链为：
  `Link6 -> plasma_tool_base_link -> plasma_adapter_link ->`
  `plasma_spray_rod_link -> Arm_Tip`。
- 已迁入当前确认需要的公共底座、2 种转接件和 12 种喷杆 STL；没有迁入
  `260612end.STL` 或 `End piece.STL`。
- `config/tool_variants.yaml` 支持 `3_4/6_8`、`150/200` 和
  `1x5/1x10/1x20` 组合；12 个组合均通过 Xacro 生成检查。
- 用户确认现场实际转接规格为 `3_4`；当前默认试验型号修正为
  `3_4 + 200_1x10`。
- 用户确认 `3_4/6_8` 不改变轴向长度。同一喷杆/喷嘴规格共用轴向 TCP；
  GUI 固定内部 `3_4`，不显示转接件或完整工具型号，只显示喷嘴总长度。
- GUI 启动时从 `tcp_3_4_200_1x10.yaml` 的 `T_gripper_to_tcp` 读取
  `Arm_Tip +Z` 方向上的喷嘴总长度；后续实测只需更新同一 YAML，GUI 与
  路径转换节点会同步，避免两处硬编码。
- 2026-07-23 新增的三张现行 DWG 已归档到
  `plasma_tool_description/reference/drawings/`。喷杆图纸标注总长 `210 mm`，
  装配时插入枪体 `10 mm`，外露仍为 `200 mm`；枪口距 Link6 为
  `78 + 40 = 118 mm`，所以正确轴向 TCP 为
  `0.118 + 0.200 = 0.318 m`。旧的 `0.304 m` 计算混用了插入起点和临时
  TCP，已经作废。TCP YAML 状态更新为 `drawing_confirmed_geometry`，完整
  安装横向偏差/姿态尚未验收，所以继续保持 `validated=false` 和仅预览状态。
- CAD 几何继续沿局部 `+Y` 装配；整套 CAD 组件相对 Link6 使用
  `Rx(+90 deg)`，将局部 `+Y` 映射到 `Link6 +Z`，末端再用
  `Rx(-90 deg)`，使 `Arm_Tip` 与 Link6 同向。
- 2026-07-23 已在真实 `ECO65-BI` 三代控制器上以 5% 速度完成
  `Arm_Tip +Z 2 mm -> -Z 2 mm` 往返点动。两次 MoveL 均成功，正向实际
  位移约 `1.98 mm`，返回位置误差约 `0.033 mm`；操作者目视确认 `+Z`
  沿喷杆轴线朝喷嘴尖端。该结果只验收工具轴方向，完整 TCP 和手眼精度尚未
  验收，`execution_permitted` 继续保持 false。
- 新增只读详细工具系结果话题
  `/rm_driver/get_current_tool_frame_data_result`。实机读回控制器 `Arm_Tip`
  的平移和欧拉角均为零；同关节角下控制器 UDP 零工具位姿与 ROS
  `baselink -> Link6` 完全一致（四元数仅整体反号）。因此控制器当前
  `Arm_Tip` 是法兰零工具，未包含 318 mm 喷嘴长度；软件继续通过
  `T_gripper_to_tcp` 反算法兰位姿，未向控制器写入 TCP。
- 名义矩阵保存为
  `plasma_tool_description/config/tcp_3_4_200_1x10.yaml`，并由
  `plasma_path_transform.launch.py` 默认加载。
- 该 TCP 仅来自 CAD，安装原点和真实喷嘴尖端未实测，保持
  `validated=false`。实测运行状态为 `tcp_loaded=true`、
  `ready_for_preview=true`、`ready_for_execution=false`；未发送运动命令。
- 型号选择、文件职责和后续实测步骤见
  `plasma_tool_description/README.md`。

### 真实机械臂自检

- GUI 注册并自动启动 `rm_driver/rm_eco65_driver.launch.py`。
- 成功条件同时要求 ROS 图存在 `/rm_driver`，且 `/joint_states` 在 1.5 秒有效期内持续提供健康的六关节数据。
- 最长等待 15 秒；失败时只停止本次自检自动启动的驱动，不停止外部已有驱动。
- 默认不再跳过机械臂；只有显式设置 `PLASMA_GUI_DEBUG_MODE=1` 才启用调试跳过。
- 2026-07-23 已在正式 GUI 中点击系统自检，自动启动相机和 ECO65 驱动，界面显示成功，日志输出“系统自检通过”。全程未发送 MoveJ、MoveL 或其他运动命令。

### C++ 坐标转换节点

正式代码均位于 `src/third_party/plasma_robot/`：

```text
plasma_robot_interfaces
tools/eye_hand (ROS 包名 plasma_eye_hand)
tools/tf/plasma_path_transform
```

固定变换链：

```text
T_base_tcp =
T_base_gripper(capture)
* T_gripper_camera(handeye)
* T_camera_tcp(path)
```

- 输入必须携带采集点云时的六关节状态，或直接携带采集时 `T_base_gripper`；禁止使用规划完成后的当前机械臂姿态替代。
- 六关节输入通过 ECO65 URDF 和 KDL 正解得到 `T_base_gripper`。
- 手眼 YAML 兼容键 `T_camera_to_gripper`，实际语义固定为 `^gripper T_camera`；TCP 键为 `T_gripper_to_tcp`。
- 标定加载支持 `validated`、文本 `status`、`quality.status`、`deployment.quality_accepted` 和 `deployment.status`。
- 没有手眼矩阵时拒绝转换；未验收矩阵只能生成 `execution_permitted=false` 的预览。
- 示例 identity 文件只说明格式，禁止用于实机运动。

ROS 接口：

```text
输入  /plasma/planned_spray_path/camera
输出  /plasma/planned_spray_path/base
状态  /plasma/path_transform/status
服务  /plasma_path_transform/transform_path
服务  /plasma_path_transform/reload_calibration
```

GUI 在暂停采集时冻结点云 `frame_id`、时间戳和当时六关节状态；规划完成后将全部路径点、姿态、阶段和开关元数据发布给转换节点。缺少采集元数据时拒绝发布。

### 文件归属与脚本清单

- 本轮正式新增的 ROS 2 包：共享接口 `plasma_robot_interfaces/`、手眼数据包 `tools/eye_hand/`、坐标转换包 `tools/tf/plasma_path_transform/`。
- 本轮新增的启动脚本：`tools/tf/plasma_path_transform/launch/plasma_path_transform.launch.py`，只启动 C++ 坐标转换节点。
- 已融入 GUI、但不是本轮生成的原厂脚本：`rm_driver/launch/rm_eco65_driver.launch.py`，用于真实机械臂自检连接。
- 原厂机械臂本体和接口：`rm_driver/`、`rm_description/`、`rm_ros_interfaces/` 等 `rm_*` 包，不属于本轮生成代码。
- `src/plasma_gui/scripts/mock_arm_joint_states.py` 只是模拟六关节数据的测试工具。
- `src/plasma_gui/scripts/single_layer_rotation_demo.py` 和 `multi_layer_rotation_demo.py` 是上一阶段实机诊断/干运行脚本，不属于正式坐标转换或喷涂位姿输出链路；正式功能不依赖它们。
- GUI 中正式接入代码仍放在 GUI 自己的职责目录：路径发布位于 `gui/mainwindow` 和 `gui/work_space/opengl/point_v2`，原有机械臂 ROS 适配位于 `module/RobotArm`。

后续目标目录结构：

```text
src/third_party/plasma_robot/
├── plasma_robot_interfaces/       # 跨模块共享 ROS 消息/服务
└── tools/
    ├── eye_hand/                  # 手眼采集、求解、验证、矩阵配置
    └── tf/                        # TF、坐标转换、路径变换工具
```

`tools/eye_hand/` 已保存 L515 `f1423110` 的 HORAUD 暂用矩阵，并整理为 ROS 数据包 `plasma_eye_hand`。`plasma_path_transform` 已迁入 `tools/tf/`，默认加载该矩阵。矩阵严格验收未通过，因此只允许预览，`execution_permitted` 保持为 false。

`plasma_eye_hand` 现已增加 C++ 只读工具 `tcp_pivot_calibrator`。它只订阅
`/rm_driver/udp_arm_position` 并由操作者按键采集法兰姿态，不发布任何运动
命令；用于从 6-10 个手动低速、多轴变化的 pivot 姿态求
`Link6 -> 喷嘴尖端` 三维平移和横向安装偏差。结果独立保存为 YAML，固定保持
`validated: false`、`execution_allowed: false`，不会自动覆盖当前 318 mm TCP。
使用步骤和输出路径见 `tools/eye_hand/README.md`。

### 构建、测试和运行时结果

- `plasma_robot_interfaces`、`plasma_path_transform`、`plasma_gui` 构建成功。
- 转换包限定结果：`8 tests, 0 errors, 0 failures, 0 skipped`。
- `plasma_eye_hand` 与迁移后的 `plasma_path_transform` 从新目录构建成功，源矩阵和安装矩阵 SHA-256 一致。
- 默认 launch 已实际加载 `l515_handeye_20260723_152410_horaud`；单位法兰姿态下，相机原点转换为 `[-0.0400500, -0.0619060, 0.0242366] m`，与 YAML 完全一致。
- 修正后 URDF 实测 `Link6 -> Arm_Tip` 为平移 `[0, 0, 0.318] m`、单位旋转。路径转换服务使用 `z=0.500 m` 的 TCP 测试点，正确得到 `z=0.182 m` 的法兰位姿；结果为 `transform_valid=true`、`flange_pose_valid=true`、`execution_permitted=false`。
- 状态话题确认机械臂模型、手眼矩阵和 TCP 均已加载，`ready_for_preview=true`、`ready_for_execution=false`；图纸推导喷嘴总长度为 `318.0 mm`，但手眼矩阵仍为暂用状态，且安装横向偏差和完整六自由度 TCP 尚未验收。
- 最新 GUI 已重新构建并实际启动，日志确认 `已加载喷嘴总长度：318.0 mm`；启动和验证过程中未发送新的 MoveJ 或 MoveL。
- `plasma_eye_hand` 的 pivot 合成数据和无驱动安全拒绝测试通过；尚未采集当前喷嘴的现场 pivot 样本。
- GUI 启动时发现并修复 Galactic 对进程内通信加 `transient_local` QoS 的不兼容。
- GUI 关闭时增加 ROS worker 和三个受管 launch 的停止等待；复测 GUI 返回码为 0，关闭后 ROS 图及设备进程全部清空。
- 当前没有运行中的 `plasma_gui`、`rm_driver`、相机或 `path_transform_node` 进程。

## 2026-07-22 上一阶段完成内容

### 独立机械臂执行步骤

- `WizardStep` 从 4 步扩展为 5 步，在 `PathPlanning` 后增加 `RobotExecution`。
- 新增“机械臂执行”流程页。页面在 `MainWindow::initStepWizard()` 中动态创建，避免直接扩充庞大的 `.ui` XML。
- 页面显示：
  - 机械臂在线状态
  - 当前选择的轨迹节点
  - 闭合层数
  - 规划层间距
  - 喷嘴总长度和当前人工入口干运行模式
  - 独立执行进度条
- 路径规划页只负责参数配置和完整轨迹生成，不再通过 `btn1` 启动机械臂。
- `btn1` 长按确认已经迁移到 `RobotExecution`；长按走满后调用已有执行确认弹窗。
- `btn2` 在机械臂页是停止按钮，会中止执行器或直接发布 `move_stop`。

### 流程状态

- 开始重新生成完整轨迹时，`PathPlanning` 和 `RobotExecution` 都重置为未完成。
- 完整轨迹的六个阶段全部成功后，才将 `PathPlanning` 标记完成并允许正常进入机械臂步骤。
- 机械臂执行成功后单独完成 `RobotExecution`。
- 机械臂执行失败、中止或急停后，`RobotExecution` 保持未完成。
- 路径参数改变后，必须重新生成完整轨迹。

### 安全入口

- 主界面急停现在会同时：
  - 关闭等离子 UI 输出状态
  - 将气体流量置零
  - 调用串口 `emergencyStop()`
  - 中止正在运行的机械臂执行器，或直接发布 `/rm_driver/move_stop_cmd`
  - 清空机械臂执行进度并将该步骤标记为未完成
- 真实等离子自动启停尚未接入机械臂执行阶段，当前仍保持关闭。

## 构建与启动结果

已执行：

```bash
colcon build --packages-select plasma_gui --event-handlers console_direct+
```

结果：成功。只有 Open3D `CMP0072` 的既有 CMake 弃用警告。

新构建 GUI 已启动，启动日志确认：

```text
StepWizard initialized with 5 steps
```

启动时没有下发 MoveJ 或 MoveL。第五步页面交互检查仍属于后续整机流程任务，不优先于当前手眼矩阵接入。

## 交接时正在运行的进程

当前没有运行中的 GUI、相机、机械臂驱动或坐标转换节点。运行时仍会看到两个同名 `/plasma_gui_node` 和 rosout 警告，这是已有节点命名问题，后续单独整理。

## 最后确认的实机状态

以下是最后一次动作后的确认值，新对话开始时必须向用户确认或读取实时状态：

- 机械臂：RealMan ECO65-BI。
- 控制器工具系：`Arm_Tip`。
- 现场已确认控制器工具 `+Z` 沿喷杆朝喷嘴尖端方向。
- 单层旋转执行成功：J6 左转半圈、回零、右转半圈、回零。
- 随后执行了两段工具 `+Z 5 mm` 的新增分层演示。
- 最后确认位置相对人工入口累计工具 `+Z 10 mm`，位于演示第三层。
- 最后确认 J6 回到末层入口角，约 `7.7 deg`。
- GUI 重启后没有再发送机械臂运动命令。
- 动作速度为 `5%`。
- 真实等离子输出关闭；用户此前说明等离子部分没有通电。

重要：不得直接重复运行多层脚本。每次运行都会继续沿工具 `+Z` 累计深入，必须先确认当前位置和剩余安全距离。

## 当前机械臂执行方式

正式 GUI 当前复用：

- `src/plasma_gui/src/module/RobotArm/arm_ros_adapter.*`
- `src/plasma_gui/src/module/RobotArm/demo_rotation_executor.*`

执行方式仍是经过实机演示验证的临时方案：

```text
人工对准第一层入口
-> 每层 J6 +180 deg
-> J6 回入口角
-> J6 -180 deg
-> J6 回入口角
-> 沿现场验证的工具轴移动到下一层
```

限制：

- 这不是模型坐标系离线位姿到机械臂基坐标系的完整转换。
- `Joint6GeometricDeg` 仍是保守几何代理，不是完整逆解结果。
- 没有完成机械臂模型碰撞检测、自动入口定位或实际等离子剂量控制。
- 当前用途是整机流程融合和低速断电干运行。

临时终端脚本仍保留，只用于诊断和现场简化演示，不作为正式 GUI 流程入口：

- `src/plasma_gui/scripts/single_layer_rotation_demo.py`
- `src/plasma_gui/scripts/multi_layer_rotation_demo.py`

## 下一步必须继续的任务

1. L515 `f1423110` 暂用矩阵已保存到 `tools/eye_hand/config/camera_to_gripper.yaml`，方向确认为 `^Link6 T_camera`，单位米。
2. 当前矩阵状态为 `user_approved_provisional_use`，严格离线验收为 false；继续进行非接触已知点验证，不得提升为正式执行状态。
3. 图纸轴向总长已修正为 `318.0 mm`，`Arm_Tip +Z` 方向已经确认；继续实测 `3_4 + 200_1x10` 的安装横向偏差和完整六自由度 TCP，修正 `T_gripper_to_tcp`。
4. TCP 实测验收后更新对应型号 YAML 并调用 `reload_calibration`，再次检查 `execution_permitted`。
5. 标定和 TCP 均验收后，确认输出从第一个喷涂起始位姿开始，且全部点的运动阶段和 `plasma_enabled` 正确。
6. 坐标链验收完成后，继续补齐机械臂故障与等离子输出的统一安全联锁。

## 本轮修改入口

- `src/third_party/plasma_robot/plasma_robot_interfaces/`
- `src/third_party/plasma_robot/tools/eye_hand/`
- `src/third_party/plasma_robot/tools/tf/plasma_path_transform/`
- `src/plasma_gui/src/gui/panel/left_panel/step_wizard/step/system_check/SystemCheckManager.*`
- `src/plasma_gui/src/gui/panel/left_panel/step_wizard/ros_launch_manager/ros_launch_manager.*`
- `src/plasma_gui/src/gui/work_space/opengl/point_v2/ros_worker.h`
- `src/plasma_gui/src/gui/panel/left_panel/dbtree/NodeCloudData.h`
- `src/plasma_gui/src/gui/mainwindow/mainwindow.*`
- `src/plasma_gui/CMakeLists.txt`
- `src/plasma_gui/package.xml`

- `src/plasma_gui/src/gui/panel/left_panel/step_wizard/StepWizardModel.h`
- `src/plasma_gui/src/gui/panel/left_panel/step_wizard/StepWizardModel.cpp`
- `src/plasma_gui/src/gui/panel/left_panel/step_wizard/StepWizardView.h`
- `src/plasma_gui/src/gui/panel/left_panel/step_wizard/StepWizardView.cpp`
- `src/plasma_gui/src/gui/mainwindow/mainwindow.h`
- `src/plasma_gui/src/gui/mainwindow/mainwindow.cpp`
- `src/plasma_gui/src/temp_ref/INTEGRATED_WORKFLOW.md`
- `src/plasma_gui/src/temp_ref/HANDOFF.md`

## 工作区警告

当前仓库非常脏，大量 `src/plasma_gui`、`src/plasma_robot` 和资源文件尚未跟踪，另有历史删除和修改。下一位处理时：

- 只修改当前任务涉及的文件。
- 不要以 `git status` 中的未跟踪状态为理由删除文件。
- 不要恢复看似“被删除”的历史文件，除非用户明确要求。
- `mainwindow.cpp/.h` 原本就包含大量用户修改并混用 CRLF/LF，避免进行整文件格式化或行尾统一。

## 新对话开场检查命令

```bash
cd /home/larusxu/CodeSpace/PlasmaRobot
sed -n '1,260p' src/plasma_gui/src/temp_ref/HANDOFF_NEW_CHAT_20260722.md
sed -n '1,220p' src/plasma_gui/src/temp_ref/INTEGRATED_WORKFLOW.md
git status --short
pgrep -af 'plasma_gui|rm_driver'
source /opt/ros/galactic/setup.bash
source install/setup.bash
ros2 node list | sort
```

新对话首先询问用户最新现场变化；如果最新信息与本文档冲突，以用户最新信息为准。当前从“导入并核对实测手眼矩阵”继续，不得先使用示例矩阵或启动自动路径运动。

## 2026-07-24 末端三对象与正式路径接口更新

本节覆盖本文前面所有把 `Arm_Tip 318 mm` 直接称为运动 TCP、把 10 mm
喷口对称套在 TCP 两端、或把喷杆半径写成 5 mm 的旧说明。

当前 `3_4 + 200_1x10` 正式几何：

```text
plasma_motion_tcp:
  Link6 轴向距离 310 mm
  +X 沿喷杆朝底部/物理前端
  +Z 指向侧面喷涂方向

plasma_safety_tip:
  motion TCP +X 8 mm
  Link6 轴向距离 318 mm

plasma_spray_outlet:
  motion TCP +Z 2 mm
  代表 3_4 喷杆侧喷口表面中心
```

路径有效范围使用非对称末端占用：

```text
开口端 = 侧喷口后半长 5 mm + 开口额外安全距离
底部端 = TCP 到安全点 8 mm + 底部额外安全距离
喷杆半径 = 2 mm
```

GUI 已改为读取 TCP YAML 的 `measurement` 字段，不再从旋转后的矩阵投影猜
工具长度；`PathPlanningTask` 和 `SlicePlanningTask` 都显式接收 5 mm/8 mm。
`NodeCloudData` 保存运动 TCP、安全点、喷口后向占用和喷杆半径元数据。

`SprayPathPoint.msg` 新增：

```text
safety_point + safety_point_valid
spray_outlet_pose + spray_outlet_pose_valid
```

`plasma_path_transform` 从同一工具 YAML 的 `T_tcp_to_safety_tip` 和
`T_tcp_to_spray_outlet` 为每个基坐标路径点生成这两项。正式
`plasma_path_executor` 会拒绝缺少有效安全点或侧喷口位姿的旧路径。

验证结果：

- 五个目标包均构建成功：`plasma_robot_interfaces`、
  `plasma_tool_description`、`plasma_path_transform`、
  `plasma_path_executor`、`plasma_gui`。
- 转换测试 8 项、执行器测试 6 项全部通过。
- 只读 ROS 服务以单位运动 TCP 检查得到安全点 `[0.008, 0, 0]`、侧喷口
  `[0, 0, 0.002]`，两项 valid 均为 true。
- 输出仍为 `execution_permitted=false`；真实运动和真实等离子输出均未开启。

正式 `plasma_path_executor` 已接入 GUI：执行页开始/停止和主急停均走正式
执行器状态/服务，旧 `DemoRotationExecutor` 不再由 GUI 创建或调用。GUI 自动
启动执行器时固定 `motion_enabled=false`，因此当前只能缓存、校验和显示路径，
不能运动。软件仍不负责机械臂初始位置到入口点的运动；第一点只用于核对人工
已经到入口。

下一步优先级：完成现场手眼、运动 TCP、安全点和侧喷口的已知点验收。只有
验收并更新 YAML 状态后，才讨论把 GUI 注册 launch 中的运动门改为 true；
即使开启，正式执行器仍只接受 `dry_run=true`，真实等离子输出保持关闭。

补充验证：已向正式执行器发布一条完整的 8 点单层合成路径，顺序为
`0 -> +180 -> 0 -> -180 -> 0`，安全点和侧喷口位姿均有效。执行器状态为
`STATE_PATH_READY`、`total_points=8`，随后因 `motion_enabled=false` 明确拒绝
开始请求；全程 `plasma_output_enabled=false`。临时执行器代码已从
`MainWindow` 删除，并从 GUI 构建源列表排除，仅保留诊断源码文件。

## 2026-07-24 末端安装尺寸最终修正

本节覆盖本文前面所有 `318/315 mm` 结论以及把圆头后方 `3 mm` 直接当成
喷口中心的结论。现场最终确认：

```text
Link6 安装基准面到圆头末端       310 mm
圆头末端到喷口近侧边               3 mm
1x10 喷口轴向长度                  10 mm
圆头末端到喷口中心                  8 mm = 3 + 10 / 2
Link6 到喷口中心轴向               302 mm
3_4 喷口表面相对喷杆轴线径向         2 mm
```

正式 `plasma_motion_tcp` 仍位于真实喷口中心，因此
`Link6 -> TCP = [0.002, 0, 0.302] m`，`TCP -> 圆头末端 =
[+0.008, 0, -0.002] m`。径向 2 mm 对远距离喷涂距离影响很小，但保留该项以
保证正负 180 度旋转围绕真实喷口中心。旧的 `重建1路径` 由错误末端几何生成，
必须作废并在新 GUI 加载修正后的 YAML 后重新规划。

## 2026-07-24 自动入口与防碰撞更新（覆盖前文旧入口说明）

当前软件已经负责从机械臂任意初始位姿到入口外法线方向 100 mm 预入口点，不再要求人工精确
摆到入口。MoveIt 先规划当前位置到预入口；从该规划的末端关节状态继续检查
`预入口 -> 入口 -> 全部喷涂点`，5 mm 笛卡尔采样必须 100% 可解且无碰撞，
否则不会签发当前路径的执行许可。GUI 会在 RViz 显示两段轨迹并要求二次确认。

下方白色机柜已经作为当前专用 URDF 的碰撞 Link：

```text
尺寸: 0.995 x 0.603 x 0.954 m
中心(baselink): [0.403, 0, -0.403] m
```

SRDF 只关闭 `baselink <-> plasma_cabinet_collision_link`，机械臂其他 Link 和
等离子末端与机柜的碰撞检查保持开启。除此之外，正式运动还增加两层运行保护：

1. RealMan 驱动设置碰撞灵敏度后立即回读，实际值必须为 8；设置或回读失败会发布
   无效值并锁住运动。
2. 每个直接 MoveL 小步开始前记录六关节电流，运动中任一关节电流幅值相对该步基准
   增加超过 1500 mA，会立即发送停止命令。电流数据或 Link6 位姿超时同样停止。

完整说明：

```text
src/third_party/plasma_robot/tools/motion/AUTOMATIC_ENTRY_WORKFLOW_20260724.md
src/third_party/plasma_robot/tools/motion/COLLISION_SAFETY_20260724.md
```

安全锁仍保持：GUI 中入口规划器和路径执行器均为 `motion_enabled=false`，手眼
`strict_quality_accepted=false`，TCP `validated=false`，因此目前只允许全路径规划、
碰撞检查和 RViz 预览，不允许绕过验收下发真实运动。

## 2026-07-25 完整路径首次现场 MoveIt 预览

`重建1路径` 的当前位置到预入口规划成功。后半段最初被 MoveIt 相对关节跳变
系数误判；探测计算显示启用或关闭碰撞均只能完成 `0.000342`，关闭相对跳变后
完成率为 `1.0`，因此不是碰撞或 IK 不可达。

入口规划器现改为保持全程碰撞检查，并对生成后的六轴轨迹执行 10 度绝对相邻
步差限制。现场重新规划结果：596 个目标位姿、3107 个关节轨迹点，最大步差
`1.900827 deg`，发生在 `joint3`，完整预览通过并进入 `STATE_PREVIEW_READY`。
当时机械臂距离预入口约 `117.9 mm`、姿态差约 `148.9 deg`；运动门和标定许可
仍为 false，未发送任何真实运动。

后续一次规划在 `joint6` 第 489 点报告 `358.999981 deg`，但 RViz 已能播放动画。
确认该值来自正负 180 度边界的等价角表示，而非真实整圈反转。入口规划器现会
依据 MoveIt/URDF 的旋转关节上下限，为每一点选择最接近上一点的等价角，并把
连续化结果写回预览轨迹，再执行 10 度绝对步差检查。若限位内没有连续等价角，
仍会拒绝路径。`plasma_path_executor` 已重新构建，本包 23 项测试全部通过；运行中
的旧 GUI/规划器必须重启后才会加载该修复。

继续实机诊断确认存在第二类 359 度问题：失败点实际为
`joint6 -359.962702 -> -0.962572 deg`。这表示 MoveIt 随机选择的预入口 IK 支路
贴近机械下限，后续负向 180 度路径没有剩余关节行程，不能用局部角度回绕修正。
同一路径换一个预入口支路即可完整通过，最大步差约 1.29 度。入口规划器已改为
自动尝试最多 8 个“入口接近 + 全部喷涂点”候选，每个候选独立执行碰撞、IK、
关节限位和 10 度步差检查，只发布完整通过的支路。现场无运动模式连续验证 4 次
全部成功，最大步差为 `1.285716-1.682803 deg`；所有真实运动锁保持关闭。

2026-07-25 将预入口由 60 mm 调整为入口外法向 100 mm，并重新生成现场
`重建1路径`：446 个位姿，第 3 个完整分支通过，最大步差 `1.512857 deg`
（joint4）。操作者已在 RViz 确认预入口到入口为正常法向直线进入，不再从下方
横移靠近组织。该确认只验收路径形状；手眼 `strict_quality_accepted=false`、TCP
`validated=false` 和两个 `motion_enabled=false` 仍保持真实运动锁定。

## 2026-07-25 首次真实机械臂运动结果

通过显式的现场调试授权，在 `5%` 速度、等离子关闭条件下，已完成
`重建1路径` 的完整规划，并让真实机械臂成功运动到入口外法向 100 mm 的预入口。
MoveIt 和控制器均报告成功，操作者已亲眼确认机械臂运动。手眼/TCP 的 YAML 验收
状态和 GUI 默认运动门没有修改。

尚未执行预入口到入口、入口到第一喷涂层以及 446 点完整路径的实机干运行。
明天应从重新读取实时机械臂位姿、重新规划和等离子关闭的完整干运行继续。

结束前已正常关闭临时的运动执行器、宽松标定转换节点、MoveIt/RViz、入口规划器和
独立 `rm_driver`，未发送回撤或其他新运动命令。GUI 和相机仍保持运行。详细记录：

```text
src/third_party/plasma_robot/tools/motion/REAL_ROBOT_PRE_ENTRY_RESULT_20260725.md
```

## 2026-07-30 入口轴向过深安全修正

现场确认入口横向位置和方向基本准确，但安装真实喷管后，旧入口轴向过深，尚未开始
喷涂就存在圆头接近底部的风险。工具尺寸没有改动，仍为 Link6 到圆头 310 mm、
Link6 到侧喷口 TCP 轴向 302 mm、TCP 到圆头轴向 8 mm。

已新增独立的圆头入口外停距离，默认 30 mm；安全入口现在让圆头停在视觉物理开口外
30 mm，而不是开口平面。真实执行拆成“当前位置到预入口、预入口到安全入口并停车、
安全入口到喷涂点”三段。GUI 必须在第二段结束后目视确认圆头仍在真实开口外，才允许
第三段。旧路径必须作废并由新 GUI 重新生成。

相关五个包构建通过，坐标转换 11 项和轨迹执行 22 项测试全部通过。详细设计、文件
分布和首次现场复验步骤见：

```text
src/third_party/plasma_robot/tools/motion/AXIAL_ENTRY_STANDOFF_20260730.md
```

## 2026-07-30 末端轴向实测再次覆盖

本节覆盖本文所有旧的 `Link6 -> TCP 302 mm / 圆头 310 mm` 活动结论。操作者重新
确认实际装配栈为：

```text
端板 8 mm + 固定罩 70 mm + 喷头本体 40 mm + 外露喷管 200 mm = 318 mm
喷管起点/喷头本体末端 = 118 mm（不是运动 TCP）
真实侧喷口中心 TCP = 318 - (3 + 10 / 2) = 310 mm
```

活动工具配置已改为 `Link6 -> TCP=[0.002, 0, 0.310] m`、圆头 `318 mm`，
`TCP -> 圆头=[+0.008, 0, -0.002] m` 保持不变。完整记录在
`plasma_tool_description/TOOL_AXIAL_REMEASUREMENT_20260730.md`。

操作者在旧 302/310 模型生成的安全入口实测到“真实侧喷口恰好位于第一喷涂层”。
该结果必须保留，但旧路径已经失效；修正后同一视觉目标对应的 Link6 位姿会沿工具轴
向外移动约 8 mm，必须重新生成路径并分别复测圆头入口位置和第一层侧喷口位置。

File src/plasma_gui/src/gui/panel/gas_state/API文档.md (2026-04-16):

# 气体状态控件 API 文档

## 概述

本文档详细说明了气体状态显示系统中两个主要控件的封装、结构和使用方法：
- `FlowDisplayWidget` - 流量显示控件
- `GasProgressWidget` - 气体进度条控件

---

## FlowDisplayWidget 流量显示控件

### 概述
`FlowDisplayWidget` 继承自 `QWidget`，专门用于显示流量数据信息，支持动态扫描动画效果。

### 头文件位置
```cpp
#include "panel/gas_state/flowdisplaywidget.h"
```

### 类声明
```cpp
class FlowDisplayWidget : public QWidget
{
    Q_OBJECT
    Q_PROPERTY(qreal scan_position READ ScanPosition WRITE SetScanPosition)

public:
    explicit FlowDisplayWidget(QWidget *parent = nullptr);
    
    // 基础接口
    void SetFlowValue(const QString &value);
    QString FlowValue() const;
    void StartScanAnimation();
    
    // 数据接口
    void SetFlowValue(double value, const QString &unit = "L/min");
    void SetFlowValueWithFormat(double value, const QString &format = "%.1f L/min");
    void SetTextColor(const QColor &color);
    void SetTextSize(int size);
    void SetTextStyle(const QColor &color, int size, bool bold = false);
    void SetBackgroundGradient(const QColor &startColor, const QColor &endColor);
    void SetBackgroundStyle(const QColor &startColor, const QColor &endColor, const QColor &borderColor);
    void SetAnimationDuration(int milliseconds);
    void SetAnimationEnabled(bool enabled);
    
    // 预设主题
    void ApplyBlueTheme();
    void ApplyGreenTheme();
    void ApplyOrangeTheme();
    void ApplyRedTheme();

protected:
    void paintEvent(QPaintEvent *event) override;
    void resizeEvent(QResizeEvent *event) override;

private slots:
    void OnAnimationFinished();

private:
    void SetupUI();
    void SetupAnimation();
    void UpdateLabelStyle();
    qreal ScanPosition() const;
    void SetScanPosition(qreal position);
};
```

### 成员变量
```cpp
private:
    QLabel *flow_label;                    // 流量显示标签
    QPropertyAnimation *scan_animation;    // 扫描动画
    QTimer *ripple_timer;                 // 波纹效果定时器
    qreal scan_position;                  // 扫描位置
    QList<QPointF> ripple_positions;      // 波纹位置列表
    
    // 样式参数
    bool animation_enabled;               // 动画开关
    QColor text_color;                   // 文本颜色
    int text_size;                       // 文本大小
    bool text_bold;                      // 文本粗体
    QColor bg_start_color;               // 背景起始颜色
    QColor bg_end_color;                 // 背景结束颜色
    QColor border_color;                 // 边框颜色
```

### 主要功能和函数

#### 1. 数据设置函数
```cpp
// 设置流量值（字符串）
void SetFlowValue(const QString &value);
// 示例：widget->SetFlowValue("15.5 L/min");

// 设置流量值（数值+单位）
void SetFlowValue(double value, const QString &unit = "L/min");
// 示例：widget->SetFlowValue(15.5, "L/min");

// 设置流量值（自定义格式）
void SetFlowValueWithFormat(double value, const QString &format = "%.1f L/min");
// 示例：widget->SetFlowValueWithFormat(15.5, "%.2f L/min");

// 启动扫描动画
void StartScanAnimation();
```

#### 2. 样式设置函数
```cpp
// 设置文本颜色
void SetTextColor(const QColor &color);
// 示例：widget->SetTextColor(QColor(255, 255, 255));

// 设置文本大小
void SetTextSize(int size);
// 示例：widget->SetTextSize(14);

// 一次设置文本样式
void SetTextStyle(const QColor &color, int size, bool bold = false);
// 示例：widget->SetTextStyle(QColor(255, 255, 255), 14, true);

// 设置背景渐变
void SetBackgroundGradient(const QColor &startColor, const QColor &endColor);
// 示例：widget->SetBackgroundGradient(QColor(0, 100, 200), QColor(0, 150, 255));

// 一次设置背景样式
void SetBackgroundStyle(const QColor &startColor, const QColor &endColor, const QColor &borderColor);
// 示例：widget->SetBackgroundStyle(QColor(0, 100, 200), QColor(0, 150, 255), QColor(100, 100, 100));
```

#### 3. 动画控制函数
```cpp
// 设置动画持续时间
void SetAnimationDuration(int milliseconds);
// 示例：widget->SetAnimationDuration(1500);

// 启用/禁用动画
void SetAnimationEnabled(bool enabled);
// 示例：widget->SetAnimationEnabled(true);
```

#### 4. 预设主题函数
```cpp
// 蓝色主题（适用于He气体）
void ApplyBlueTheme();

// 绿色主题（适用于正常运行状态）
void ApplyGreenTheme();

// 橙色主题（适用于警告状态）
void ApplyOrangeTheme();

// 红色主题（适用于错误状态）
void ApplyRedTheme();
```

---

## GasProgressWidget 气体进度条控件

### 概述
`GasProgressWidget` 继承自 `QWidget`，专门用于显示气体容量的垂直进度条，支持自动颜色变化和状态检测。

### 头文件位置
```cpp
#include "panel/gas_state/gasprogresswidget.h"
```

### 类声明
```cpp
class GasProgressWidget : public QWidget
{
    Q_OBJECT

public:
    explicit GasProgressWidget(QWidget *parent = nullptr);
    
    // 基础接口
    void SetValue(int value);
    void SetMaximum(int maximum);
    void SetMinimum(int minimum);
    void SetProgressColor(const QColor &color);
    void SetBackgroundColor(const QColor &color);
    void SetCornerRadius(int radius);
    
    // 数据接口
    void SetValueWithRange(int value, int min, int max);
    void SetPercentage(double percentage);
    double GetPercentage() const;
    void SetBorderColor(const QColor &color);
    void SetSize(int width, int height);
    void SetFullStyle(const QColor &progressColor, const QColor &bgColor, const QColor &borderColor, int radius);
    
    // 预设样式
    void ApplyHeGasStyle();
    void ApplyArGasStyle();
    void ApplyWarningStyle();
    void ApplyNormalStyle();
    
    // 气体状态管理
    void SetGasStatus(double pressure, int volume, double flowRate, int ratio);
    void SetLowVolumeWarning(bool enabled, int threshold = 20);
    bool IsLowVolume() const;
    bool IsEmpty() const;
    QString GetStatusText() const;
    QString GetVolumeStatusText() const;

protected:
    void paintEvent(QPaintEvent *event) override;

private:
    void UpdateColorByValue();
};
```

### 成员变量
```cpp
private:
    int value;                           // 当前值
    int minimum;                         // 最小值
    int maximum;                         // 最大值
    int corner_radius;                   // 圆角半径
    QColor progress_color;               // 进度条颜色
    QColor background_color;             // 背景颜色
    QColor border_color;                 // 边框颜色
    
    // 扩展属性
    bool low_volume_warning_enabled;     // 低容量警告开关
    int low_volume_threshold;            // 低容量阈值
    double gas_pressure;                 // 气体压力
    double gas_flow_rate;               // 气体流量
    int gas_ratio;                      // 气体比例
```

### 主要功能和函数

#### 1. 数据设置函数
```cpp
// 设置当前值
void SetValue(int value);
// 示例：widget->SetValue(75);

// 设置最大值
void SetMaximum(int maximum);
// 示例：widget->SetMaximum(100);

// 设置最小值
void SetMinimum(int minimum);
// 示例：widget->SetMinimum(0);

// 同时设置值和范围
void SetValueWithRange(int value, int min, int max);
// 示例：widget->SetValueWithRange(75, 0, 100);
```

#### 2. 百分比操作函数
```cpp
// 设置百分比值
void SetPercentage(double percentage);
// 示例：widget->SetPercentage(75.0);

// 获取当前百分比
double GetPercentage() const;
// 示例：double percent = widget->GetPercentage();
```

#### 3. 样式设置函数
```cpp
// 设置进度条颜色
void SetProgressColor(const QColor &color);
// 示例：widget->SetProgressColor(QColor(33, 150, 243));

// 设置背景颜色
void SetBackgroundColor(const QColor &color);
// 示例：widget->SetBackgroundColor(QColor(51, 51, 51));

// 设置边框颜色
void SetBorderColor(const QColor &color);
// 示例：widget->SetBorderColor(QColor(85, 85, 85));

// 设置圆角半径
void SetCornerRadius(int radius);
// 示例：widget->SetCornerRadius(10);

// 设置控件尺寸
void SetSize(int width, int height);
// 示例：widget->SetSize(20, 100);

// 一次设置完整样式
void SetFullStyle(const QColor &progressColor, const QColor &bgColor, const QColor &borderColor, int radius);
// 示例：widget->SetFullStyle(QColor(33, 150, 243), QColor(51, 51, 51), QColor(85, 85, 85), 10);
```

#### 4. 预设样式函数
```cpp
// He气样式（蓝色）
void ApplyHeGasStyle();

// Ar气样式（绿色）
void ApplyArGasStyle();

// 警告样式（橙色）
void ApplyWarningStyle();

// 正常样式（绿色）
void ApplyNormalStyle();
```

#### 5. 气体状态管理函数
```cpp
// 一次设置气体状态
void SetGasStatus(double pressure, int volume, double flowRate, int ratio);
// 示例：widget->SetGasStatus(12.5, 75, 8.2, 53);
// 参数：压力(MPa), 容量(%), 流量(L/min), 比例(%)

// 设置低容量警告
void SetLowVolumeWarning(bool enabled, int threshold = 20);
// 示例：widget->SetLowVolumeWarning(true, 20); // 启用警告，阈值20%

// 检查是否为低容量
bool IsLowVolume() const;
// 示例：if (widget->IsLowVolume()) { /* 处理低容量 */ }

// 检查是否为空
bool IsEmpty() const;
// 示例：if (widget->IsEmpty()) { /* 处理空状态 */ }

// 获取状态文本
QString GetStatusText() const;
// 返回值：「空」、「低」、「中」、「高」、「满」等

// 获取容量状态文本
QString GetVolumeStatusText() const;
// 返回值：容量: 75% (正常)
```

---

## 使用示例

### 1. FlowDisplayWidget 使用示例

#### 基础使用
```cpp
// 创建控件
FlowDisplayWidget* flowWidget = new FlowDisplayWidget(parent);

// 设置流量值
flowWidget->SetFlowValue("15.5 L/min");
flowWidget->SetFlowValue(15.5, "L/min");

// 应用主题
flowWidget->ApplyBlueTheme();

// 启动动画
flowWidget->StartScanAnimation();
```

#### 自定义样式
```cpp
FlowDisplayWidget* customWidget = new FlowDisplayWidget(parent);

// 自定义样式
customWidget->SetTextStyle(QColor(255, 255, 255), 16, true);
customWidget->SetBackgroundStyle(
    QColor(0, 100, 200),    // 起始颜色
    QColor(0, 150, 255),    // 结束颜色
    QColor(100, 100, 100)   // 边框颜色
);
customWidget->SetAnimationDuration(2000);
customWidget->SetFlowValue(18.7, "L/min");
```

### 2. GasProgressWidget 使用示例

#### 基础使用
```cpp
// 创建He气体进度条
GasProgressWidget* heWidget = new GasProgressWidget(parent);
heWidget->ApplyHeGasStyle();
heWidget->SetGasStatus(12.5, 75, 8.2, 53);

// 创建Ar气体进度条
GasProgressWidget* arWidget = new GasProgressWidget(parent);
arWidget->ApplyArGasStyle();
arWidget->SetGasStatus(8.3, 45, 7.3, 47);
```

#### 状态检查
```cpp
GasProgressWidget* gasWidget = new GasProgressWidget(parent);
gasWidget->SetLowVolumeWarning(true, 20);
gasWidget->SetValue(15);

// 检查状态
if (gasWidget->IsLowVolume()) {
    qDebug() << "警告：" << gasWidget->GetVolumeStatusText();
    gasWidget->ApplyWarningStyle();
}

if (gasWidget->IsEmpty()) {
    qDebug() << "气体容量已耗尽";
    gasWidget->ApplyRedTheme();
}
```

### 3. 在MainWindow中的集成使用

```cpp
void MainWindow::SetupGasStatusDisplay()
{
    // 流量显示设置
    ui->flowDisplayWidget->ApplyBlueTheme();
    ui->flowDisplayWidget->SetFlowValue(15.5, "L/min");
    ui->flowDisplayWidget->SetAnimationDuration(1200);
    
    // He气体进度条设置
    ui->heProgressWidget->ApplyHeGasStyle();
    ui->heProgressWidget->SetGasStatus(12.5, 75, 8.2, 53);
    ui->heProgressWidget->SetLowVolumeWarning(true, 20);
    
    // Ar气体进度条设置
    ui->arProgressWidget->ApplyArGasStyle();
    ui->arProgressWidget->SetGasStatus(8.3, 45, 7.3, 47);
    ui->arProgressWidget->SetLowVolumeWarning(true, 15);
}

void MainWindow::UpdateGasStatus()
{
    // 动态更新
    double currentFlow = getCurrentFlowRate();
    ui->flowDisplayWidget->SetFlowValue(currentFlow, "L/min");
    
    // 更新He气状态
    ui->heProgressWidget->SetGasStatus(
        getHePressure(),
        getHeVolume(),
        getHeFlowRate(),
        getHeRatio()
    );
    
    // 状态检查
    if (ui->heProgressWidget->IsLowVolume()) {
        showWarning("He气容量不足：" + ui->heProgressWidget->GetVolumeStatusText());
    }
}
```

---

## 注意事项

1. **动画性能**：FlowDisplayWidget的动画会消耗一定的CPU资源，在性能敏感的场合下可以通过`SetAnimationEnabled(false)`关闭动画。

2. **颜色自动变化**：GasProgressWidget在设置百分比数值时，进度条会自动调整颜色，手动设置的颜色可能会被覆盖。

3. **线程安全**：这些控件应在主线程中使用，如果需要在其他线程中更新数据，请使用Qt的信号槽机制。

4. **内存管理**：控件会自动管理内部的动画和定时器对象，无需手动释放。

5. **样式继承**：预设主题会覆盖之前的自定义样式设置。

---

## 版本信息

- **版本**：1.0
- **创建日期**：2024年
- **兼容版本**：Qt 6.x
- **依赖**：QtWidgets, QtCore, QtGui

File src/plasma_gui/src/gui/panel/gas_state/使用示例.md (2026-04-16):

# 气体状态控件使用示例

## FlowDisplayWidget 流量显示控件

### 基础使用
```cpp
// 创建控件
FlowDisplayWidget* flowWidget = new FlowDisplayWidget(parent);

// 设置流量值
flowWidget->SetFlowValue("15.5 L/min");
flowWidget->SetFlowValue(15.5, "L/min");
flowWidget->SetFlowValueWithFormat(15.5, "%.1f L/min");
```

### 样式设置
```cpp
// 设置文本样式
flowWidget->SetTextColor(QColor(255, 255, 255));
flowWidget->SetTextSize(14);
flowWidget->SetTextStyle(QColor(255, 255, 255), 14, true);

// 设置背景样式
flowWidget->SetBackgroundGradient(QColor(0, 100, 200), QColor(0, 150, 255));
flowWidget->SetBackgroundStyle(QColor(0, 100, 200), QColor(0, 150, 255), QColor(100, 100, 100));
```

### 动画控制
```cpp
// 设置动画
flowWidget->SetAnimationDuration(1500);
flowWidget->SetAnimationEnabled(true);
```

### 预设主题
```cpp
// 应用预设主题
flowWidget->ApplyBlueTheme();    // 蓝色主题
flowWidget->ApplyGreenTheme();   // 绿色主题
flowWidget->ApplyOrangeTheme();  // 橙色主题
flowWidget->ApplyRedTheme();     // 红色主题
```

### 完整示例
```cpp
// 完整的He气体流量显示
FlowDisplayWidget* heFlowWidget = new FlowDisplayWidget(parent);
heFlowWidget->ApplyBlueTheme();
heFlowWidget->SetFlowValue(8.2, "L/min");
heFlowWidget->SetAnimationDuration(1200);

// 完整的Ar气体流量显示
FlowDisplayWidget* arFlowWidget = new FlowDisplayWidget(parent);
arFlowWidget->ApplyGreenTheme();
arFlowWidget->SetFlowValue(7.3, "L/min");
arFlowWidget->SetAnimationEnabled(false);
```

## GasProgressWidget 气体进度条控件

### 基础使用
```cpp
// 创建控件
GasProgressWidget* gasWidget = new GasProgressWidget(parent);

// 设置数值
gasWidget->SetValue(75);
gasWidget->SetValueWithRange(75, 0, 100);
gasWidget->SetPercentage(75.0);
```

### 样式设置
```cpp
// 设置颜色
gasWidget->SetProgressColor(QColor(33, 150, 243));
gasWidget->SetBackgroundColor(QColor(51, 51, 51));
gasWidget->SetBorderColor(QColor(85, 85, 85));
gasWidget->SetCornerRadius(10);

// 一次设置完整样式
gasWidget->SetFullStyle(QColor(33, 150, 243), QColor(51, 51, 51), QColor(85, 85, 85), 10);

// 设置尺寸
gasWidget->SetSize(20, 100);
```

### 预设样式
```cpp
// 应用预设样式
gasWidget->ApplyHeGasStyle();      // He气样式（蓝色）
gasWidget->ApplyArGasStyle();      // Ar气样式（绿色）
gasWidget->ApplyWarningStyle();    // 警告样式（橙色）
gasWidget->ApplyNormalStyle();     // 正常样式（绿色）
```

### 气体状态管理
```cpp
// 一次设置气体状态（压力、容量、流量、比例）
gasWidget->SetGasStatus(12.5, 75, 8.2, 53);

// 设置低容量警告
gasWidget->SetLowVolumeWarning(true, 20);  // 启用警告，阈值20%
```

### 状态查询
```cpp
// 查询状态
double percentage = gasWidget->GetPercentage();
bool isLow = gasWidget->IsLowVolume();
bool isEmpty = gasWidget->IsEmpty();
QString status = gasWidget->GetStatusText();
QString volumeStatus = gasWidget->GetVolumeStatusText();
```

### 完整使用示例
```cpp
// He气体进度条控件
GasProgressWidget* heProgressBar = new GasProgressWidget(parent);
heProgressBar->ApplyHeGasStyle();
heProgressBar->SetGasStatus(12.5, 75, 8.2, 53);
heProgressBar->SetLowVolumeWarning(true, 20);

// Ar气体进度条控件
GasProgressWidget* arProgressBar = new GasProgressWidget(parent);
arProgressBar->ApplyArGasStyle();
arProgressBar->SetGasStatus(8.3, 45, 7.3, 47);
arProgressBar->SetLowVolumeWarning(true, 15);

// 检查状态
if (heProgressBar->IsLowVolume()) {
    qDebug() << "He气体容量不足:" << heProgressBar->GetVolumeStatusText();
}
```

## 在MainWindow中的使用建议

### 替换原有的复杂创建代码
```cpp
// 原来的代码（复杂）
void MainWindow::SetupGasStatusDisplay()
{
    // 创建流量显示FlowDisplayWidget
    flow_display_widget = new FlowDisplayWidget(ui->gasStatusWidget);
    flow_display_widget->SetFlowValue("15.5 L/min");
    // ... 更多的参数设置代码 ...
    
    // 创建He气体进度条
    he_progress_bar = new GasProgressWidget(ui->gasStatusWidget);
    he_progress_bar->SetProgressColor(QColor(33, 150, 243));
    he_progress_bar->SetValue(75);
    // ... 更多的参数设置代码 ...
}

// 新的代码（简洁）- 推荐使用Qt Designer设计控件
void MainWindow::SetupGasStatusDisplay()
{
    // 直接操作界面上的控件
    ui->flowDisplayWidget->ApplyBlueTheme();
    ui->flowDisplayWidget->SetFlowValue(15.5, "L/min");
    
    ui->heProgressWidget->ApplyHeGasStyle();
    ui->heProgressWidget->SetGasStatus(12.5, 75, 8.2, 53);
    
    ui->arProgressWidget->ApplyArGasStyle();
    ui->arProgressWidget->SetGasStatus(8.3, 45, 7.3, 47);
}
```

### 动态更新示例
```cpp
void MainWindow::UpdateGasStatus()
{
    // 更新流量显示
    ui->flowDisplayWidget->SetFlowValue(getCurrentFlowRate(), "L/min");
    
    // 更新He气状态
    ui->heProgressWidget->SetGasStatus(
        getHePressure(),
        getHeVolume(),
        getHeFlowRate(),
        getHeRatio()
    );
    
    // 检查气体状态
    if (ui->heProgressWidget->IsLowVolume()) {
        showWarning("He气体容量不足");
    }
}
```

## 优化效果

1. **代码简洁**：复杂的创建代码变为一行调用
2. **类型安全**：避免了字符串拼接和格式化错误
3. **功能丰富**：提供了更多数据的管理选项
4. **便于维护**：统一的接口方法，便于后期修改
5. **预设主题**：快速应用常用的样式配置

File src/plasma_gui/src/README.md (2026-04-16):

## 命名规范总结
### 1. 类名命名
- 使用PascalCase（首字母大写的驼峰）
- 注意：那三个opengl的类，尾部的gl不参与分割
- 例如： ApplicationManager , ProcessConfig , ProcessType
### 2. 函数/方法命名
- 使用PascalCase（首字母大写的驼峰）
- 例如： StartProcess() , StopProcess() , ConfigureProcess()
### 3. 成员变量/普通变量/常量命名
- 使用小写字母，用下划线分隔
- 例如： config_set , process_manager , display_name , auto_start

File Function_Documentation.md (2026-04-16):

# 点云交互功能文档 (Point Cloud Interaction Documentation)

本文档描述了 PlasmaRobot 项目中点云交互功能的实现细节和使用说明。

## 1. 功能概述

在主界面右侧布局中，移除了原有的 `pointcloud_gl` 和 `robotarm_gl` 控件，替换为一组点云交互按钮。主要提供以下三个功能：

1.  **裁剪 (Crop)**: 使用 3D 包围盒 (Box Widget) 对点云进行裁剪。
2.  **移动 (Move)**: 使用 3D 包围盒对点云进行平移和旋转操作。
3.  **标注 (Label)**: 点击点云上的点，显示该点的坐标信息。

## 2. 实现细节

### 2.1 UI 更改 (`mainwindow.ui`)

-   **移除**: `rightLayout` 中的 `PointCloudgl` 和 `RobotArmgl`。
-   **新增**: `QGroupBox` (标题 "点云交互")，包含三个 `QPushButton`:
    -   `btnCrop`: 开启裁剪模式。
    -   `btnMove`: 开启移动模式。
    -   `btnLabel`: 开启标注模式。

### 2.2 核心逻辑 (`main_gl.cpp` / `main_gl.h`)

`MainOpengl` 类（继承自 `QVTKOpenGLNativeWidget`）负责具体的 VTK 交互实现。

#### 引入的 VTK 组件
-   `vtkBoxWidget2` / `vtkBoxRepresentation`: 用于裁剪和移动的交互框。
-   `vtkPointPicker`: 用于拾取点云上的点。
-   `vtkCaptionActor2D`: 用于显示标注文本。
-   `vtkExtractGeometry` / `vtkPlanes`: 用于裁剪计算（目前实现为视觉裁剪）。

#### 主要接口
-   `void EnableCrop(bool enable)`: 启用/禁用裁剪模式。
-   `void EnableMove(bool enable)`: 启用/禁用移动模式。
-   `void EnableLabel(bool enable)`: 启用/禁用标注模式。

#### 回调函数实现
1.  **CropCallback**:
    -   监听 `vtkBoxWidget2` 的交互事件。
    -   获取 Box 的平面 (`GetPlanes`)。
    -   设置 Actor Mapper 的裁剪平面 (`SetClippingPlanes`)，实现实时视觉裁剪。

2.  **MoveCallback**:
    -   监听 `vtkBoxWidget2` 的交互事件。
    -   获取 Box 的变换矩阵 (`GetTransform`)。
    -   应用变换到点云 Actor (`SetUserTransform`)，实现点云随框移动。

3.  **LabelCallback**:
    -   监听鼠标左键点击事件 (`LeftButtonPressEvent`)。
    -   使用 `vtkPointPicker` 获取点击位置的世界坐标。
    -   创建 `vtkCaptionActor2D` 在点击位置显示坐标 (X, Y, Z)。

### 2.3 信号与槽 (`mainwindow.cpp`)

在 `MainWindow` 中连接了 UI 按钮的 `toggled` 信号到相应的处理函数：
-   `OnCropToggled`: 互斥地开启裁剪模式。
-   `OnMoveToggled`: 互斥地开启移动模式。
-   `OnLabelToggled`: 互斥地开启标注模式。

## 3. 使用说明

1.  **加载点云**: 程序启动时会自动加载默认点云（或通过代码指定）。
2.  **裁剪**:
    -   点击右侧面板的“裁剪”按钮。
    -   主视图中会出现一个白色线框盒。
    -   拖动盒子的面或控制点来调整裁剪范围，点云会被实时裁剪。
    -   再次点击按钮取消模式（裁剪效果保留）。
3.  **移动**:
    -   点击“移动”按钮。
    -   出现控制盒，拖动盒子可平移或旋转整个点云。
4.  **标注**:
    -   点击“标注”按钮。
    -   在点云上点击任意位置，会生成一个红色标签，显示该点的坐标。

## 4. 依赖库

-   VTK (Visualization Toolkit) 8.x/9.x
-   PCL (Point Cloud Library)
-   Qt 5/6

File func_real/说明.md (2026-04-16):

本项目采用的VTK，PCL和Qt版本及相应地址

Qt版本：6.7.2

VTK版本：9.3.0
VTK：https://github.com/Kitware/VTK
学习：https://examples.vtk.org/site/

PCL版本：1.15.0
github：https://github.com/PointCloudLibrary/pcl?tab=readme-ov-file
文档：https://pcl.readthedocs.io/projects/tutorials/en/master/
api查询：https://pointclouds.org/documentation/

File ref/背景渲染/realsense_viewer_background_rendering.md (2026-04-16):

# RealSense Viewer 3D 渲染环境与视角控制分析

本文档详细分析 RealSense Viewer 在 3D 点云显示模式下的**背景渲染**、**栅格绘制**以及**视角控制（居中显示）**的实现方案。

## 1. 背景渲染 (Background Rendering)

RealSense Viewer 的 3D 视图背景并非单一颜色，而是由一个纯色背景和一个可选的“天空盒”组成，营造出空间感。

### 1.1 清除颜色 (Clear Color)
在每一帧渲染开始时，OpenGL 视口会被清除为全黑。

*   **代码位置**: `common/viewer.cpp` -> `viewer_model::render_3d_view`
*   **实现**:
    ```cpp
    // common/viewer.cpp:1994
    glClearColor(0, 0, 0, 1);
    glClear(GL_COLOR_BUFFER_BIT | GL_DEPTH_BUFFER_BIT);
    ```

### 1.2 天空盒 (Skybox)
为了提供更好的 3D 观感，Viewer 默认开启了一个“天空盒”。这是一个包围相机的巨大立方体，内壁贴有 6 张无缝衔接的纹理图片。

*   **核心类**: `skybox` (定义在 `common/skybox.h`, 实现在 `common/skybox.cpp`)
*   **调用位置**:
    ```cpp
    // common/viewer.cpp:2024
    if (show_skybox) _skybox.render(pos);
    ```
*   **实现原理**:
    1.  **资源加载**: 构造函数中从内存（`res/nx.h` 等头文件中硬编码的 PNG 数据）加载 6 张图片（前后左右上下）到 OpenGL 纹理。
    2.  **渲染**: `skybox::render` 函数接受当前相机位置 `cam_position`。
    3.  **跟随相机**: 使用 `glTranslatef` 将立方体移动到相机位置，确保相机永远位于立方体中心。
    4.  **绘制**: 使用 `GL_QUAD_STRIP` 绘制立方体的 6 个面，并贴上对应的纹理。

## 2. 栅格渲染 (Grid Rendering)

Viewer 在 3D 空间底部绘制了一个网格（Grid），作为参考平面（通常代表地平面 Y=0 或 Z=0，视坐标系而定）。

### 2.1 基础绘制函数
在 `common/rendering.h` 中定义了一个通用的 `draw_grid` 函数，用于简单的调试绘制。

```cpp
// common/rendering.h:912
void draw_grid(float step)
{
    glBegin(GL_LINES);
    // ... 双重循环绘制线条 ...
    glEnd();
}
```

### 2.2 主视图栅格实现
在主 3D 视图中，栅格的绘制逻辑更加定制化，位于 `viewer_model::render_3d_view` 函数中。

*   **代码位置**: `common/viewer.cpp` (约 2139 行)
*   **特性**:
    *   **自适应单位**: 根据 `metric_system`（公制/英制）调整网格大小。
    *   **中心线高亮**: 中心线使用较亮的灰色 `(0.7, 0.7, 0.7)`，其他线使用较暗的灰色 `(0.4, 0.4, 0.4)`。
    *   **位置**: 绘制在 Y=1 的平面上（可能是为了适应相机的默认俯视角度）。

```cpp
// common/viewer.cpp 片段
glTranslatef(0, 0, -1);
glBegin(GL_LINES);
// ...
for (int i = 0; i <= ceil(tiles); i++)
{
    // 设置颜色：中心线高亮
    if (i == tiles / 2) glColor4f(0.7f, 0.7f, 0.7f, 1.f);
    else glColor4f(0.4f, 0.4f, 0.4f, 1.f);
    
    // 绘制线条
    glVertex3f(I - T, 1, -T);
    glVertex3f(I - T, 1, T);
    // ...
}
glEnd();
```

## 3. 视角居中与控制 (Camera Control)

RealSense Viewer 如何保证点云显示在界面中间，以及如何响应用户的鼠标操作，主要依赖于**ArcBall 相机模型**和**自动重置逻辑**。

### 3.1 视角重置 (Reset Camera)
当用户点击“Reset View”按钮或初始化时，会调用 `reset_camera` 函数。

*   **代码位置**: `common/viewer.cpp` -> `viewer_model::reset_camera`
*   **实现逻辑**:
    1.  **目标点归零**: 将相机看向的目标点 (`target`) 设置为世界坐标原点 `(0, 0, 0)`。
    2.  **位置设置**: 将相机位置 (`pos`) 设置为传入的初始位置（通常是 Z 轴负方向某处）。
    3.  **上方向计算**: 重新计算 `up` 向量，确保相机姿态正确。

```cpp
void viewer_model::reset_camera(float3 p)
{
    target = { 0.0f, 0.0f, 0.0f }; // 居中目标
    pos = p;
    // ... 计算 up 向量 ...
}
```

### 3.2 保持居中 (Center View)
Viewer 并没有实时强制“锁定”点云在屏幕中心（用户可以自由拖动）。但在以下情况会自动调整：
1.  **启动时**: 调用 `reset_camera`。
2.  **切换流时**: 如果检测到新的流配置，可能会重置视角。
3.  **鼠标操作**: 使用 `arcball_camera` 算法（包含在 `common/viewer.h` 中引用的 `arcball_camera.h`），该算法围绕 `target` 点进行旋转。因为 `target` 默认是 `(0,0,0)`，所以旋转操作会给人一种“围绕点云中心”的感觉。

### 3.3 智能交互 (Picking)
为了增强控制感，Viewer 支持鼠标拾取（Picking）。
*   当用户双击或操作时，会通过 `_pc_renderer` (Point Cloud Renderer) 获取鼠标点击处的 3D 坐标。
*   代码逻辑会更新 `target` 到点击的 3D 点，从而改变旋转中心，让用户能方便地观察特定区域。

```cpp
// common/viewer.cpp:2271
_measurements.mouse_pick(win, p, normal);
// Adjust track-ball controller based on picked position
```

## 4. 总结

*   **背景**: 黑色清屏 + Skybox 立方体贴图。
*   **参考系**: 手动绘制的 GL_LINES 网格。
*   **居中**: 通过将 ArcBall 相机的 `target` 设置为 `(0,0,0)` 并配合 `reset_camera` 函数实现。

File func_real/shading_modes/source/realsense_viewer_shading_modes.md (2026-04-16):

# RealSense Viewer 3D 着色模式实现流程分析

本文档详细分析了 RealSense SDK v2.51.1 中 `realsense-viewer` 的 3D 视图着色模式实现，包括 "Raw Point-Cloud"（原始点云）、"Flat-Shaded Mesh"（平面着色网格）和 "With Diffuse Lighting"（漫反射光照）三种模式。

## 1. 概述与模式映射

在 `realsense-viewer` 的 UI 中，三种模式对应代码中的 `shader_type` 枚举。

**文件位置**: `common/viewer.h`

```cpp
enum class shader_type {
    points,  // 对应 "Raw Point-Cloud"
    flat,    // 对应 "Flat-Shaded Mesh"
    diffuse  // 对应 "With Diffuse Lighting"
};
```

## 2. UI 交互与状态切换

用户点击界面上的 Shading 按钮时，会触发 ImGui 的菜单逻辑，更新 `selected_shader` 变量。

**文件位置**: `common/viewer.cpp`

关键代码片段（逻辑示意）：

```cpp
// 在 viewer_model 类的绘制逻辑中
if (ImGui::MenuItem("Raw Point-Cloud", nullptr, &selected))
{
    if (selected) selected_shader = shader_type::points;
}
if (ImGui::MenuItem("Flat-Shaded Mesh", nullptr, &selected))
{
    if (selected) selected_shader = shader_type::flat;
}
if (ImGui::MenuItem("With Diffuse Lighting", nullptr, &selected, glsl_available))
{
    if (selected) selected_shader = shader_type::diffuse;
}
```

## 3. 渲染参数设置 (Render 3D View)

`viewer_model::render_3d_view` 函数负责根据当前的 `selected_shader` 状态，配置点云渲染器 (`_pc_renderer`) 的选项。

**文件位置**: `common/viewer.cpp`
**函数**: `viewer_model::render_3d_view`

该函数通过设置两个关键选项来控制渲染器的行为：
1.  `OPTION_FILLED`: 控制是画点（Points）还是画填充三角形（Mesh）。
2.  `OPTION_SHADED`: 控制是否启用着色器中的光照计算。

```cpp
// 核心逻辑
_pc_renderer.set_option(gl::pointcloud_renderer::OPTION_FILLED, selected_shader != shader_type::points ? 1.f : 0.f);
_pc_renderer.set_option(gl::pointcloud_renderer::OPTION_SHADED, selected_shader == shader_type::diffuse ? 1.f : 0.f);
```

| 模式名称 | shader_type | OPTION_FILLED | OPTION_SHADED | 效果 |
| :--- | :--- | :--- | :--- | :--- |
| Raw Point-Cloud | `points` | 0 (False) | 0 (False) | 绘制离散点，无光照 |
| Flat-Shaded Mesh | `flat` | 1 (True) | 0 (False) | 绘制三角网格，使用纹理颜色，无光照 |
| With Diffuse Lighting | `diffuse` | 1 (True) | 1 (True) | 绘制三角网格，叠加漫反射光照计算 |

## 4. 渲染器实现 (Pointcloud Renderer)

`pointcloud_renderer` 类负责执行具体的 OpenGL 绘制命令。它位于 `src/gl` 目录下，属于 OpenGL 功能模块。

**文件位置**: `src/gl/pc-shader.cpp`
**类**: `pointcloud_renderer`

在 `process_frame` 或绘制相关的方法中，根据 `OPTION_FILLED` 决定绘制方式：

```cpp
// 伪代码逻辑示意
if (_filled_opt->query() > 0.f)
    _model->draw();        // 绘制三角形 (GL_TRIANGLES) - 对应 Mesh 模式
else
    _model->draw_points(); // 绘制点 (GL_POINTS) - 对应 Point-Cloud 模式
```

同时，它会将 `OPTION_SHADED` 的值传递给 GLSL 着色器。

```cpp
shader->set_shaded(_shaded_opt->query());
```

## 5. GLSL 着色器实现 (Shader Implementation)

核心的光照计算逻辑位于 GLSL 片段着色器代码中。

**文件位置**: `src/gl/pc-shader.cpp`

在代码中，着色器源码通常以字符串形式存储（如 `fragment_shader_text`）。

### 漫反射光照算法 (Diffuse Lighting)

当 `shaded` 参数大于 0 时，启用光照计算。代码定义了三个固定的光源方向，计算法线与光源方向的点积（Lambertian reflectance），混合得到最终亮度。

```glsl
// 片段着色器核心逻辑
if (shaded > 0.0) {
    // 定义三个光源方向
    vec3 light0 = vec3(0.0, 1.0, 0.0);
    vec3 light1 = vec3(0.5, -1.0, 0.0);
    vec3 light2 = vec3(-0.5, -1.0, 0.0);

    // 计算当前片元到光源的方向
    vec3 light_dir0 = light0 - vec3(outPos);
    vec3 light_dir1 = light1 - vec3(outPos);
    vec3 light_dir2 = light2 - vec3(outPos);

    // 计算漫反射系数 (Normal dot LightDir)
    float diffuse_factor0 = max(dot(normal,light_dir0), 0.0);
    float diffuse_factor1 = max(dot(normal,light_dir1), 0.0);
    float diffuse_factor2 = max(dot(normal,light_dir2), 0.0);

    // 混合光照强度
    float diffuse_factor = 0.6 + diffuse_factor0 * 0.2 + diffuse_factor1 * 0.2 + diffuse_factor2 * 0.2;

    // 应用光照到纹理颜色
    color = clamp(diffuse_factor, 0.0, 1.0) * color;
}

## 5. 多线程与并发实现分析

在功能实现过程中，RealSense Viewer 采用了典型的**主线程渲染 + 工作线程处理**的模式：

1.  **UI交互与渲染 (主线程)**:
    *   用户在界面上选择 "Shading" 模式（`shader_type`）的操作完全在主 UI 线程（Main Thread）处理。
    *   `viewer_model::render_3d_view` 函数由主渲染循环调用，负责设置 OpenGL 状态和 Uniform 变量。
    *   OpenGL 的绘制调用（Draw Calls）必须在持有 GL Context 的线程（通常是主线程）执行。

2.  **数据生成 (工作线程)**:
    *   虽然 Shading 模式主要涉及渲染阶段，但其依赖的点云数据（Geometry）是由后台工作线程生成的。
    *   `post_processing_filters` 类中持有一个 `processing_block`，通过 `start()` 方法启动一个独立的工作线程。
    *   在该线程中，`pointcloud::process_frame`（或 `gl::pointcloud`）负责将深度图转换为点云数据（如果是 CPU 模式）或准备 GL 纹理（如果是 GPU 模式）。

3.  **线程同步**:
    *   主线程和工作线程之间通过 `rs2::frame_queue` 进行通信。工作线程生成数据后放入队列，主线程在渲染前从队列取出最新帧。
    *   这种设计保证了 UI 的高响应性，即使点云计算耗时较高，也不会卡顿界面。

### 总结

要在自己的项目中复现该功能，你需要：
1.  **构建点云网格**：不仅需要顶点位置（XYZ），还需要生成网格索引（Indices）以构成三角形（用于 Mesh 模式）。
2.  **计算法线**：光照计算依赖于顶点或面法线（Normal），需要在几何着色器或预处理阶段计算好。
3.  **移植 Shader**：将 `src/gl/pc-shader.cpp` 中的 GLSL 代码移植到你的渲染管线中。
4.  **控制逻辑**：实现类似的 Uniform 变量控制（`filled` 和 `shaded` 开关）。

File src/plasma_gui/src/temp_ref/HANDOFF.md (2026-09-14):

# Plasma GUI Handoff

本文档记录当前代码中的流程卡片、DB 树、点云/mesh/路径规划数据流，以及下一位程序员继续开发必须知道的入口。只描述当前最终状态。

> 当前最高优先级已经切换为整机流程融合：相机采集与重建 -> 机械臂执行 -> 等离子处理。实施顺序、暂停项和完成标准统一记录在 [INTEGRATED_WORKFLOW.md](./INTEGRATED_WORKFLOW.md)。恢复开发时必须先继续该文档中最后一个未完成项。
>
> 新对话请优先阅读 [HANDOFF_NEW_CHAT_20260722.md](./HANDOFF_NEW_CHAT_20260722.md)，其中包含最新代码改动、运行进程、实机最后位置和下一步检查。

## 任务连续性约定

- 任何进行中的任务如果因上下文切换、工具会话结束、程序异常或其他原因中断，恢复后必须先核对上次进度，并从中断处继续完成该任务。
- 不得把未完成的任务标记为完成，不得静默跳过未完成任务，也不得在未说明原因的情况下直接开始后续任务。
- 恢复工作时必须检查已修改文件、尚未完成的步骤、最近一次构建/测试结果，以及是否仍有命令或程序正在运行。
- 若中断前的实现只完成了几何预览或占位逻辑，恢复时必须保留其“不可执行”状态说明，直到机械臂位姿、逆解、碰撞检查和实际执行链路全部验证完成。
- 当前已经生成“左转半圈 -> 断能回零 -> 右转半圈 -> 断能回零”的离线几何位姿序列，但仍不得误写为可下发的机械臂轨迹；后续手眼标定、工具坐标变换、逆解、退刀和碰撞检查同样受上述中断恢复规则约束。

## 算法参考文件

外部 MATLAB 示例和测试数据已统一归档到 `src/plasma_gui/src/temp_ref/`：

- `cavity_reference_axis_matlab.m`：残腔中心轴计算参考。
- `cavity_slicing_planes_matlab_fixed.m`：切片平面生成参考。
- `cavity_section_contour_bspline_fit_v8.m`：切片轮廓 B 样条拟合参考。
- `cavity_equal_dose_and_path_from_v8_manual_region_overlay_v6.m`：等剂量面、分区和喷杆路径生成参考。
- `u1.txt`：MATLAB 示例的历史分区点云测试数据，仅保留作离线对照；当前 GUI 不再加载或显示它。

## 当前操作流程（快速查看）

下面是从程序启动到完整喷涂轨迹预览及第一层旋转演示的操作顺序。

1. 系统自检
   - 在 `系统自检` 流程卡片中点击 `btn1` 开始自检。
   - 当前 debug mode 可以跳过设备自检；点击下一步时会提示当前处于调试模式。

2. 残腔采集
   - 进入 `残腔采集` 页面后，实时点云默认持续刷新。
   - 点击 `btn1` 暂停实时点云，再使用点云裁剪工具选择需要保留的区域。
   - 裁剪确认后点击 `btn2`，将当前结果保存为 `残腔采集` 下的新关键帧。
   - 保存完成后自动恢复实时点云显示，可继续采集下一帧。

3. 残腔重建
   - 点击下一步会停止实时点云显示并进入 `残腔重建`。
   - 右键 `残腔采集` 下的关键帧，选择 `重建`。
   - 等待流程卡片进度条完成；重建 mesh 会加入 `残腔重建` 节点。
   - 右键新生成的重建节点，选择 `术区选择`。
   - 使用矩形或多边形框选核心术区，点击裁剪工具条中的勾确认。
   - 术区确认后，选中 mesh 使用淡橙色显示，并允许进入下一步。

4. 路径规划参数配置
   - 点击下一步进入 `路径规划` 页面。
   - 点击流程卡片中的 `btn2` 打开参数配置窗口。
   - 参数窗口按 `术区与喷嘴`、`切片范围`、`喷嘴路径`、`连续执行` 分组，只保留操作者需要的参数；算法细节使用内部默认值。

5. 生成参考轴
   - 右键 `残腔重建` 下已经完成术区选择的节点，选择 `路径规划`。
   - 线程池完成计算后，结果加入 `轨迹生成`，命名为 `重建节点名 + 路径`。
   - 勾选该轨迹节点后显示蓝色加粗直参考轴；其两端按当前喷嘴端部轴向尺寸和底部/开口安全距离裁剪，红色弯曲中心线默认隐藏，可通过右键菜单切换。

6. 生成切片平面
   - 右键 `轨迹生成` 子节点，选择 `生成切片平面`。
   - 切片起止范围、平面尺寸和绿色定向包围盒均以已选择的核心术区 mesh 为准，不再覆盖完整重建 mesh。
   - 第一个切片平面显示为半透明红色，其余切片平面显示为半透明蓝色，定向包围盒显示为绿色。

7. 生成原始切片轮廓
   - 右键同一个 `轨迹生成` 子节点，选择 `生成切片轮廓`。
   - 程序计算各切片平面与术区 mesh 的交线，结果显示为黄色轮廓。

8. 拟合切片轮廓
   - 右键同一个 `轨迹生成` 子节点，选择 `拟合切片轮廓`。
   - 线程池逐层完成闭合/开口判断、角度分箱、平滑、B 样条拟合和开口端曲率清理。
   - 拟合结果显示为青色加粗轮廓，并叠加在黄色原始轮廓上。
   - 每个闭合拟合轮廓会显示一个洋红色旋转起点：蓝色直参考轴的 `+u` 法线与该层轨迹的交点。
   - 路径规划卡片底部的进度条实时更新，主日志框输出各层拟合状态。

9. 生成喷杆几何路径预览
   - 普通流程无需单独执行；`生成完整喷涂轨迹` 会自动进入该阶段。需要单步调试时，在 `高级处理` 中选择 `生成喷杆几何路径`。
   - 线程池根据青色拟合轮廓生成分区等剂量带状面、红色逐层喷杆路径和绿色层间连接线。
   - 可在右键菜单中分别显示或隐藏等剂量面和喷杆路径。
   - 当前结果是几何路径预览，尚不能直接下发机械臂。

10. 生成分段连续路径
   - 右键同一个 `轨迹生成` 子节点，选择 `生成分段连续路径`。
   - 机械臂末端存在线缆缠绕约束，关节 6 每个执行段最多只能转半圈，因此闭合 360 度路径会至少拆成两个执行段。
   - 线程池按局部周向累计转角拆分路径，并在精确的 180 度边界插值；分段处显示白色关节 6 复位标记。
   - 洋红色粗线为处理段，黄色线为正常层间移动，红色线为超过配置阈值的异常层间移动。
   - 生成后原始红色喷杆路径自动隐藏，可通过右键菜单显示或隐藏整套分段连续路径。
   - 当前只生成分段几何和复位标记，不包含安全退刀、关节 6 回绕动作、喷杆姿态、逆解或碰撞检查，不能直接执行。

11. 生成喷嘴位姿
   - 右键同一个 `轨迹生成` 子节点，选择 `生成喷嘴位姿`。
   - 每个闭合层以洋红色旋转起点为零度，按 `左转 0→180° -> 断能回零 -> 右转 0→-180° -> 断能回零` 生成离线几何位姿；开口层暂不套用完整旋转并会跳过。
   - 每个位姿保存蓝轴上的 TCP、喷嘴方向、轴向、四元数、层号、几何转角、运动阶段和等离子启停状态；层间以零度姿态沿蓝轴移动。
   - 视图稀疏显示每层四个唯一方向的彩色喷嘴箭头：`0°/+90°/±180°共用方向/-90°`，可通过右键菜单隐藏或显示。
   - 当前位姿仍在模型坐标系中，未经过机器人基坐标变换、真实 TCP 标定、逆解或碰撞检查，不能直接执行。

12. 手动入口的逐层旋转干运行
   - 本功能只用于实机演示，不等同于将模型坐标系中的喷嘴位姿直接下发机械臂。
   - 在 DB 树中单击已经生成喷嘴位姿的 `轨迹生成` 子节点，再长按路径规划卡片的 `btn1`，直至进度条走满。
   - 软件从 `nozzlePoseSequence` 的每个闭合层提取左右半圈角度和蓝轴上的 TCP；没有喷嘴位姿、没有有效左右半圈或没有选中轨迹节点时禁止执行。
   - 操作者必须先通过示教器将机械臂移动到第一层入口，并让喷嘴对准洋红色旋转起点。软件不负责从初始姿态移动到入口。
   - 确认弹窗显示轨迹生成时保存的等离子工具型号、法兰到喷嘴 TCP、喷嘴端部轴向尺寸和模型深入轴，并自动查询控制器当前工具坐标系。工具系查询、MoveL 接口或结果话题未就绪时禁止进入执行。
   - 控制器层移工具 X/Y/Z 轴及同向/反向均不设默认值。选择候选轴后，使用弹窗中的 `+1mm / -1mm` 按钮完成一次往返点动；第一次点动后只能反向返回，回到测试起点后该轴才被标记为已验证。
   - 点动速度固定为 `5%`，下发前同样要求 `/joint_states` 在 `1.5s` 内有效。点动失败或 `15s` 超时会发送 `/rm_driver/move_stop_cmd`，将位置标记为未知并禁止本次继续执行。点动尚未返回测试起点时，不能切换轴或确认执行。
   - 每层以最新 `/joint_states` 为入口零位，保持该层 `J1-J5` 不变，按 `J6 左转 -> 回零 -> J6 右转 -> 回零` 执行；层间断能并通过 `/rm_driver/movel_offset_cmd` 沿工具坐标轴平移，MoveJ/MoveL 速度均固定为 `5%`。
   - MoveL 成功后必须再收到一帧新的 `/joint_states`，该状态才会成为下一层基线。每一层开始前都重新校验 J6 左右目标是否在 `+-360°` 内。
   - 真实等离子输出始终关闭，日志中的喷涂启停只是阶段提示。
   - 执行前要求 `/joint_states` 在 `1.5s` 内有效，且真实驱动同时存在 `/rm_driver/movej_cmd` 订阅端和 `/rm_driver/movej_result` 发布端。模拟关节状态不能单独触发实机动作。
   - 多层执行还要求发现 `/rm_driver/movel_offset_cmd` 和 `/rm_driver/movel_offset_result`。四代控制器使用原生 `rm_movel_offset`；三代控制器不支持该 SDK 接口，驱动会读取当前位姿，通过 `rm_algo_pose_move` 计算工具/工作坐标偏移目标，再用 `rm_movel` 执行兼容直线运动。每段失败、超过 `90s`、MoveL 后 `2.5s` 内没有新关节状态或执行期间关节状态中断时，向 `/rm_driver/move_stop_cmd` 发送停止命令。
   - 2026-07-22 实机只读查询已确认当前设备为 `ECO65-BI`、三代控制器（controller version/generation 均为 `3`），当前控制器工具系为 `Arm_Tip`。原生 `rm_movel_offset` 的首次 1 mm 验证被控制器拒绝后，已采用上述三代兼容实现；重新构建后的驱动启动、控制器代际识别和工具系查询均已验证，兼容 MoveL 的实机 1 mm 往返仍需在开阔位置低速确认。
   - 当前 Eco65 的 J6 软件限位按 URDF 的 `+-360°` 检查，每个方向的单段旋转不允许超过 `180°`。
   - 轨迹节点必须保存生成时的工具型号、法兰到喷嘴 TCP、喷嘴端部轴向尺寸、工具深入轴、底部安全距离和切片间距。蓝轴生成时已从底面退让 `喷嘴端部轴向尺寸/2 + 底部安全距离`；执行前还会确认每层 TCP 同时满足轴向范围和径向贴轴要求，任一层不满足即禁止实机执行。
   - 层间距离必须大于 `1 um` 且不超过路径参数中的层间距离阈值，执行器另有 `50 mm` 硬上限。当前默认阈值为 `15 mm`。

13. 首次多层实机验证
   - 保持等离子电源物理禁用，先只选择一层，确认 `左半圈 -> 回零 -> 右半圈 -> 回零` 与线缆约束一致。
   - 单层通过后，在喷嘴远离工件的位置打开执行确认弹窗。确认自动显示的控制器工具系名称，选择候选轴并通过 `+1mm / -1mm` 往返点动确定与蓝轴重合的轴和正负方向。
   - 轴向确认后再选择两层，只验证一次层间移动；不要第一次就执行全部层。
   - 用示教器将第一层 TCP 和喷嘴零方向对准后，确认弹窗中的首个层间指令约等于规划切片间距，通常为 `5 mm`。
   - 当前动态 URDF 的喷杆深入轴是 `tcp_link` 局部 `+Y`，但 MoveL 使用的是机械臂控制器当前激活的工具坐标系。交接包没有启动时创建或切换喷杆工具坐标系的步骤，因此二者不能默认视为一致；旧固定模型中的 TCP 链接名是 `spray_tcp_link`。
   - 物理急停必须可立即触达。两层方向和距离验证正确后，才逐步增加执行层数。
   - 当前手眼矩阵尚未通过固定标定板一致性验证，不得用于自动绝对入口定位；现阶段仅采用手动首层对准加工具坐标相对层移。

控制器工具坐标系查询命令：

```bash
ros2 topic echo /rm_driver/get_current_tool_frame_result
ros2 topic pub --once /rm_driver/get_current_tool_frame_cmd std_msgs/msg/Empty "{}"
```

执行模块位于：

- `src/plasma_gui/src/module/RobotArm/arm_ros_adapter.*`：封装 RealMan MoveJ、工具坐标 MoveL、当前工具系查询、结果和运动停止话题。
- `src/plasma_gui/src/module/RobotArm/demo_rotation_executor.*`：逐层四段旋转、层间移动、关节基线更新、新鲜度监控、超时和进度。
- `MainWindow::onRequestPathExecution()`：轨迹数据检查和执行确认弹窗。
- `MainWindow::initArmMotionExecution()`：GUI 日志、进度和 ROS 适配器连接。

轨迹节点的普通右键菜单为：

```text
生成完整喷涂轨迹
显示内容 >
高级处理 >
删除
```

`生成完整喷涂轨迹` 会自动串行执行切片平面、切片轮廓、轮廓拟合、喷杆几何路径、分段连续路径和喷嘴位姿。流程卡片进度条显示六个阶段的总进度；中途失败会停在对应阶段。完成后默认隐藏中间结果，只保留蓝色参考轴和喷嘴位姿。

当前结果的颜色含义：

- 淡橙色半透明表面：选中的核心术区 mesh。
- 蓝色粗直线：按喷嘴端部轴向半尺寸和两端安全距离裁剪后的喷嘴中心安全轴段。
- 红色细曲线：弯曲中心线，默认隐藏。
- 红色半透明平面：第一个切片平面。
- 蓝色半透明平面：其余切片平面。
- 绿色线框：定向包围盒。
- 黄色轮廓：原始 mesh/切片平面交线。
- 青色粗轮廓：B 样条拟合结果。
- 洋红色大点：每层左转/右转半圈共用的旋转起点。
- 六色半透明带状面：按手动角度范围划分的喷涂分区预览，不代表物理等剂量。
- 红色粗线：各切片层的喷杆路径。
- 绿色粗线：相邻切片层之间的连接线。
- 洋红色粗线：受关节 6 半圈约束的分段处理路径。
- 黄色/红色连接线：正常/超长层间移动。
- 白色大点：关节 6 需要复位的分段位置。
- 洋红色箭头：每层零度喷嘴方向。
- 青绿色箭头：左转方向的 `+90°` 关键姿态。
- 橙色箭头：右转方向的 `-90°` 关键姿态。
- 浅蓝色箭头：空间上重合的 `+180/-180°` 共用方向。

结果失效规则：

- 重新生成切片平面时，旧黄色轮廓和旧青色拟合轮廓会被清除。
- 重新生成原始切片轮廓时，旧青色拟合轮廓会被清除。
- 重新生成切片平面、原始轮廓或拟合轮廓时，旧喷杆几何路径结果会被清除。
- 重新生成切片、轮廓、喷杆几何路径或分段连续路径时，旧喷嘴位姿会被清除。
- 删除正在计算的节点后，任务完成回调不会重新创建该节点的渲染数据。

## 流程卡片

流程由 `StepWizardModel` 管理，枚举在：

- `src/plasma_gui/src/gui/panel/left_panel/step_wizard/StepWizardModel.h`
- `src/plasma_gui/src/gui/panel/left_panel/step_wizard/StepWizardModel.cpp`

当前步骤：

1. `SystemCheck`：系统自检
   - `btn1` 是自检启动按钮。
   - 当前 MainWindow 初始化中开启了 debug mode，可跳过系统自检。

2. `CloudCapture`：残腔采集
   - 提示：请将末端相机移动至残腔上方合适的位置，以便采集残腔空间信息。
   - `btn1` 用于暂停/恢复实时点云帧显示。
   - `btn2` 用于确认裁剪后的关键帧。
   - 实时帧暂停/恢复使用 ROS topic 显示暂停逻辑，不应停止 camera 进程。

3. `CloudRebuild`：残腔重建
   - 提示：请在残腔采集序列中，右键选择合适的关键帧进行重建及术区选择。
   - 页面下方有重建进度条。
   - 右键 `残腔采集` 子节点：`重建 / 裁剪 / 删除`。
   - 右键 `残腔重建` 子节点：进入路径规划步骤前只显示 `术区选择 / 删除`；进入路径规划步骤后显示 `路径规划 / 术区选择 / 删除`。
   - 术区选择完成后，`CloudRebuild` 被标记为完成，允许进入下一步。

4. `PathPlanning`：路径规划
   - 提示：右键重建帧进行路径规划，并配置等离子参数，检查无误后即可执行！！！
   - 页面下方有路径规划进度条。
   - `btn1` 是执行确认按钮，需要长按，进度条走满后输出测试执行日志。
   - `btn2` 是路径参数配置按钮，点击弹出参数窗口。注意：`btn2` 只应在路径规划页可点击，采集页另有自己的确认逻辑。

`StepWizardView` 负责 UI 切换：

- `updateSystemCheckPage()`
- `updateCloudCapturePage()`
- `updateCloudRebuildPage()`
- `updatePathPlanningPage()`

## DB 树结构

DB 树相关文件：

- `src/plasma_gui/src/gui/panel/left_panel/dbtree/DbtreeModel.*`
- `src/plasma_gui/src/gui/panel/left_panel/dbtree/DbtreeView.*`
- `src/plasma_gui/src/gui/panel/left_panel/dbtree/NodeCloudData.h`

当前顶层节点：

- `残腔采集`
- `残腔重建`
- `轨迹生成`

`NodeCloudData` 是核心数据结构，当前包含：

- `polyData`：原点云
- `meshPolyData` / `meshFilePath`：重建 mesh
- `surgicalPointCloud` / `surgicalMesh`：术区选择结果
- `pathSampleCloud`：路径规划重采样点云
- `curvedAxis`：弯曲中心线
- `straightAxis`：按喷嘴端部轴向半尺寸和两端安全距离裁剪后的直参考轴
- `slicePlanes / firstSlicePlane / sliceBoundingBox`：切片平面与定向包围盒
- `sliceContours`：切片平面与术区 mesh 的原始交线
- `fittedSliceContours`：按层 B 样条拟合后的平滑轮廓
- `rotationStartMarkers`：蓝色直参考轴 `+u` 法线与各闭合拟合轨迹的交点
- `equalDoseSurface`：带 `RegionId` 和 cell color 的分区等剂量面
- `sprayPath`：各层喷杆路径
- `sprayPathConnections`：相邻层连接线
- `continuousSprayPath`：带 `SegmentId / SliceIndex / ClosedLayer / Joint6SweepDeg` 的分段处理路径
- `continuousPathTransitions`：带距离、起止切片和异常标记的层间移动线
- `joint6ResetMarkers`：同层路径分段处的关节 6 复位标记
- `nozzlePoseSequence`：离线六维几何位姿；点数据包含 `SequenceIndex / SliceIndex / MotionPhase / PlasmaEnabled / Joint6GeometricDeg / NozzleDirection / AxisDirection / QuaternionXYZW / TargetPoint`
- `nozzlePosePreview`：每层四个唯一方向的稀疏彩色喷嘴方向箭头输入
- `showCurvedAxis`：轨迹节点下是否显示弯曲中心线，默认 false
- `showSliceLayers`：统一控制切片平面、切片定向框、黄色节点框和黄色原始轮廓
- `showFittedContours`：统一控制拟合轮廓和洋红色旋转起点
- `showEqualDoseSurface / showSprayPath`：喷涂分区面和喷杆几何路径显隐状态
- `showContinuousPath`：分段路径、层间移动和复位标记的统一显隐状态
- `showNozzlePoses`：喷嘴位姿箭头显隐状态
- `surgicalMeshOpacity`：术区 mesh 高亮透明度
- `plannedNozzleLength`：规划时使用的喷嘴端部轴向尺寸，不是整根喷杆或法兰到 TCP 的长度
- `plannedToolVariant / plannedToolTcpOffset / plannedToolAxis`：轨迹生成时固化的等离子工具组合、法兰到喷嘴 TCP 和喷杆深入轴

路径规划完成后，不在原 `残腔重建` 子节点上显示路径。会复制一份数据加入 `轨迹生成` 子节点，命名规则：

```text
重建节点名 + 路径
```

例如：`重建1路径`。

`轨迹生成` 子节点右键菜单：

- `生成完整喷涂轨迹`：按固定依赖顺序自动生成全部结果
- `显示内容`：带勾选状态的二级菜单，可分别控制切片层与原始轮廓、拟合轮廓与旋转起点、喷涂分区面、喷杆几何路径、分段连续路径、喷嘴位姿和弯曲中心线
- `高级处理`：保留六个单步算法入口，供调试和局部重新生成使用
- `删除`

完整生成结束后默认只显示蓝色加粗直参考轴和喷嘴位姿；其他结果可从 `显示内容` 重新打开。

## 点云显示与裁剪

OpenGL 入口：

- `src/plasma_gui/src/gui/work_space/opengl/point_v2/main_gl.*`

关键接口：

- `showPointCloud(std::shared_ptr<NodeCloudData>)`
- `setPointCloudVisible(std::shared_ptr<NodeCloudData>, bool)`
- `setCurvedAxisVisible(std::shared_ptr<NodeCloudData>, bool)`
- `startSurgicalAreaSelection(std::shared_ptr<NodeCloudData>)`
- `showPathPlanningResult(...)`

当前显示约定：

- 术区 mesh：淡橙色，轨迹节点中透明度更低，便于突出路径轴线。
- 直参考轴：蓝色，加粗。
- 弯曲中心线：红色，细线，默认隐藏。

## 残腔重建

重建由 `PointDeal` 的线程池执行：

- `CloudRebuildTask`
- `PointDeal::requestCloudRebuild(...)`

MainWindow 入口：

- `onRequestCloudRebuild(...)`
- `onReconstructionProgress(...)`
- `onReconstructionLog(...)`
- `onReconstructionFinished(...)`

重建完成后通过 `DbtreeView::addRebuildMesh(...)` 加入 `残腔重建` 节点。

## 术区选择

术区选择入口：

- DB 树右键 `术区选择`
- `MainWindow::onRequestSurgicalAreaSelection(...)`
- `MainOpengl::startSurgicalAreaSelection(...)`

选择确认后：

- 同时裁剪原点云和重建 mesh。
- 当前界面只高亮术区 mesh。
- 术区 mesh 存入 `NodeCloudData::surgicalMesh`。
- 原重建节点保留术区数据，后续路径规划以 `surgicalMesh` 为输入。

## 路径参数配置

路径规划步骤下，点击 `btn2` 调用：

- `MainWindow::showPathParamDialog()`

窗口当前只显示以下功能参数：

- `术区与喷嘴`：术区处理等级；转接件 `3/4 / 6/8`；喷杆标称长度 `150 / 200mm`；喷嘴端部规格 `1x5 / 1x10 / 1x20mm`。
- `切片范围`：自动计算的切片间距；可分别配置喷嘴到底部、喷嘴到开口的安全距离。首次实机演示默认底部 `10mm`、开口 `5mm`，界面范围 `0.5-50mm`；若有效深度不足，算法拒绝生成，不会自动缩小安全距离。
- `喷嘴路径`：自动计算的喷嘴端部轴向尺寸、路径半径、法兰到喷嘴 TCP；喷杆深入轴固定显示为工具局部 `+Y`。
- `连续执行`：关节 6 单段最大转角、最大层间连接距离、切片执行顺序。

工具规格来自交接包：

```text
/home/larusxu/CodeSpace/robot_arm_handoff_20260721/
  plasma_ws/src/plasma_urdf_v2/config/tool_variants.yaml
```

默认组合为 `3_4_150_1x5`。当前工程的动态启动链为 `rm_eco65_bringup -> real_moveit_demo.launch.py -> tool_variants.yaml`，该组合加载 `78 + 30 + 143.5 = 251.5mm`，并带有对应工具的显示和碰撞 mesh。因此 GUI 默认实机工具固化为 `3_4_150_1x5 / 251.5mm / 工具局部 +Y`；其他组合可以生成路径预览，但启动参数和执行校验同步前禁止实机执行。

交接包中的旧固定启动链使用 `rm_eco65_with_shell.urdf.xacro`，其中几何偏移为 `78 + 30 + 150 = 258mm`，而且部分惯性字段与默认工具名称不一致。旧固定链与当前动态模型不能混用。实机演示应在机械臂侧使用当前工程源码并显式启动：

```bash
ros2 launch rm_bringup rm_eco65_bringup.launch.py \
  tool_enabled:=true \
  use_printed_part:=false \
  adapter_variant:=3_4 \
  rod_variant:=3_4_150_1x5
```

正式 L515 交接文档中的 pivot TCP `106.830mm` 属于当时的标定笔尖，不是等离子喷杆 TCP。代码规格不能替代现场量具确认；首次运动前必须核对实物组合和法兰到喷嘴尖端的实际距离。

喷嘴端部规格是几何主参数。选择宽度 `d` 后自动设置：

- 切片间距和喷嘴端部轴向包络为 `d`。
- 喷嘴外半径为 `d / 2`。
- 蓝色直参考轴和切片中心的开口端、底部端均让出 `d / 2 + 对应端安全距离`；蓝线表示喷嘴中心允许经过的安全轴段。
- 等剂量路径使用两端安全距离的较小值进行径向检查：`术区轮廓半径 - 路径半径 >= 检查间隙`，不满足时停止生成并输出实际最小间隙。
- 修改 btn2 参数不会原地篡改已有轨迹节点；需要重新右键重建节点执行 `路径规划`，以重新生成蓝色安全轴段及其后续派生结果。旧轨迹没有工具规格元数据时禁止实机执行。

不再显示在窗口中的算法参数继续使用代码默认值：中心轴体素 `0.001m`、候选百分位 `75`、分层 `60`、截面半宽 `0.002m`、中心线点数 `120`、平滑窗口 `7`；切片平面缩放 `1.08`；B 样条点数 `320`、闭合阈值 `0.80`、轮廓平滑窗口 `7`、角度分箱 `1度`；闭合/开口路径采样 `180/120`；连续路径最小点间距 `0.0001m`，开口层自动反向保持开启。角度分区参数沿用 MATLAB 示例值。

如果直接右键重建节点执行路径规划但还没配置参数，会提示：

```text
请先配置路径参数！
```

## 路径规划算法

算法在线程池中执行：

- `PathPlanningTask`
- `PointDeal::requestPathPlanning(...)`

当前算法实现参考 MATLAB 示例 `cavity_reference_axis_matlab.m`，主要流程：

1. 从 `surgicalMesh` 提取三角面和边界边。
2. 按三角面面积进行表面重采样，生成 `pathSampleCloud`。
3. 对 mesh 表面进行体素化。
4. 对表面体素做一圈膨胀，增强闭合性。
5. 从体素网格外边界 flood fill 外部空间。
6. 将非外部空间视为实体体素，完成内部填充。
7. 对实体体素计算欧氏近似距离场。
8. 按中心候选百分位提取中心候选点。
9. 从 mesh 边界边中提取最大开口边界。
10. 拟合开口平面法向，并根据 mesh 中心确定深度方向。
11. 剔除开口附近不稳定中心候选点。
12. 沿深度方向分层提取中心点。
13. 对弯曲中心线做移动平均和平滑重采样。
14. 对平滑弯曲中心线做 PCA，得到指向残腔内部的直参考轴方向。
15. 将术区 mesh 投影到该方向，并在开口端、底部端分别扣除 `喷嘴半长 + 对应安全距离`，得到蓝色安全轴段。
16. 输出弯曲中心线和裁剪后的直参考轴；若安全参数占满术区深度则终止并提示减小参数。

注意：

- 如果体素尺寸过小导致体素数量过大，代码会自动放大体素尺寸，并在日志中打印调整后的尺寸。
- 当前距离场是 C++ 中的欧氏近似实现，不依赖 MATLAB Image Processing Toolbox。

## 路径规划结果

路径规划完成回调：

- `MainWindow::onPathPlanningFinished(...)`

结果处理：

1. 从 `m_pathPlanningSources` 找到原重建节点数据。
2. 新建一份 `NodeCloudData`。
3. 复制原重建 mesh、术区 mesh、路径采样点云、弯曲线、直轴。
4. 设置：
   - `showCurvedAxis = false`
   - `surgicalMeshOpacity = 0.28`
5. 调用 `DbtreeView::addTrajectoryPath(sourceName, pathData)` 加入 `轨迹生成`。

只有勾选 `轨迹生成` 下的路径节点，才会显示路径结果。

## 切片平面生成

参考算法：

- `src/plasma_gui/src/temp_ref/cavity_slicing_planes_matlab_fixed.m`

入口：

- `轨迹生成` 子节点右键 `生成切片平面`
- `MainWindow::onRequestSlicePlanning(...)`
- `MainOpengl::requestSlicePlanning(...)`
- `PointDeal::requestSlicePlanning(...)`
- `SlicePlanningTask`

当前 C++ 实现：

1. 从直参考轴得到残腔轴向 `a`。
2. 用弯曲中心线首尾方向统一 `a` 为指向残腔内部。
3. 在垂直于 `a` 的横截面上对 mesh 投影点做 PCA，获得 `u/v` 局部基。
4. 将 mesh 投影到 `u/v/a` 局部坐标系，得到定向包围盒范围。
5. 根据开口和底部安全距离生成有效轴向区间。
6. 首个切片位于 `bottomLimit - 0.5 * sliceSpacing`。
7. 其余切片按固定间距向开口方向排列。
8. 生成普通切片、首个切片和定向包围盒 VTK 几何。

显示约定：

- 普通切片：半透明蓝色。
- 首个切片：半透明红色。
- 定向包围盒：绿色线框。
- 切片结果存入当前轨迹节点的 `slicePlanes / firstSlicePlane / sliceBoundingBox`。
- 切片显隐跟随轨迹节点复选框。

## 切片轮廓

生成切片平面后，右键同一轨迹节点选择 `生成切片轮廓`。

算法在 `SliceContourTask` 中执行：

1. 遍历首切片和其余切片平面。
2. 从每个平面四边形取原点和法向。
3. 用 VTK Cutter 计算平面与 `surgicalMesh` 的交线。
4. 用 VTK Stripper 拼接连续线段。
5. 汇总所有有效切片轮廓到 `NodeCloudData::sliceContours`。
6. 轮廓在 OpenGL 中显示为亮黄色线。

入口：

- `MainWindow::onRequestSliceContours(...)`
- `MainOpengl::requestSliceContours(...)`
- `PointDeal::requestSliceContours(...)`
- `SliceContourTask`

## B 样条轮廓拟合

生成黄色切片轮廓后，右键同一 `轨迹生成` 子节点选择 `拟合切片轮廓`。

算法参考：

- `src/plasma_gui/src/temp_ref/cavity_section_contour_bspline_fit_v8.m`

算法在线程池的 `ContourFittingTask` 中执行：

1. 按原始轮廓 cell data 中的 `SliceIndex` 分组，每层保留最长的连续轮廓。
2. 根据直参考轴和弯曲轴方向建立局部轴向坐标系。
3. 将每层点按极角排序，并根据最大角度空隙判断该层为闭合层或开口层。
4. 开口层从最大角度空隙之后开始排序，避免跨越 0/360 度时顺序断裂。
5. 对候选点进行角度分箱取均值，再做闭合环形或开口移动平均。
6. 使用 `vtkParametricSpline` 分别执行闭合或开放 B 样条拟合。
7. 开口层按 MATLAB 示例计算离散曲率，检测端部峰值并寻找曲率恢复点，限制最大裁剪量和最少保留点数。
8. 输出轮廓写入 `NodeCloudData::fittedSliceContours`，并保留 `SliceIndex` 和 `ClosedLayer` cell data。
9. 对每个闭合层，以蓝色直参考轴为轴线建立稳定的 `u/v` 横向基，计算 `+u` 法线射线与拟合轮廓的最近正向交点，写入 `rotationStartMarkers`。开口层不生成完整旋转起点。

入口：

- `MainWindow::onRequestContourFitting(...)`
- `MainOpengl::requestContourFitting(...)`
- `PointDeal::requestContourFitting(...)`
- `ContourFittingTask`

显示约定：

- 黄色粗线：原始 mesh/切片平面交线。
- 青色加粗线：B 样条拟合后的分层轮廓。
- 洋红色大点：闭合层的统一旋转起点；左转半圈和回到起点后的右转半圈均以此点为基准。
- 重新生成切片平面会清除旧原始轮廓和拟合轮廓；重新生成原始轮廓会清除旧拟合轮廓。
- 拟合进度复用路径规划流程卡片底部的进度条，关键阶段和逐层结果写入主日志框。

## 喷杆几何路径与分区预览

普通流程由 `生成完整喷涂轨迹` 自动调用。单步调试时，完成青色 B 样条轮廓后，在 `高级处理` 中选择 `生成喷杆几何路径`。

算法参考：

- `src/plasma_gui/src/temp_ref/cavity_equal_dose_and_path_from_v8_manual_region_overlay_v6.m`

算法在线程池的 `EqualDosePathTask` 中执行：

1. 按 `SliceIndex` 读取拟合轮廓，并通过 `ClosedLayer` 区分闭合层和开口层。
2. 使用与轮廓拟合一致的直参考轴局部坐标系。
3. 闭合层按周向角周期 PCHIP 重采样，开口层展开角度后 PCHIP 重采样。
4. 根据喷杆外半径在每个角度生成喷杆路径点。
5. 将拟合轮廓沿轴向上下各扩展半个喷嘴长度，生成每层带状面。
6. 将手动角度范围按观察方向、增长方向和零度偏移转换，为面片写入 `RegionId` 和 MATLAB `lines` 风格颜色。
7. 第一有效开口层可使用首端或末端作为连接基准，其余层选择最接近参考角的路径点。
8. 将相邻层基准点连接成绿色层间连接线。

入口：

- `MainWindow::onRequestEqualDosePath(...)`
- `MainOpengl::requestEqualDosePath(...)`
- `PointDeal::requestEqualDosePath(...)`
- `EqualDosePathTask`

结果写入当前 `NodeCloudData`，不会新建 DB 树子节点。六色半透明表面是手动角度分区预览，红色线为喷杆几何路径，绿色线为层间连接；三者可在 `显示内容` 中控制。

当前限制：

- 当前“等剂量”来自几何带状面和手动角度分区，并没有物理剂量场模型。
- 当前路径只有位置点，没有喷杆姿态。
- 已进行基于局部轮廓和圆柱喷嘴外半径的径向安全间隙检查，但尚未进行完整喷嘴姿态、机械臂模型碰撞、越界、速度、停留时间和功率映射。
- 该结果只能用于预览，不能直接下发机械臂。

## 分段连续路径与关节 6 限制

完成等剂量路径后，右键同一 `轨迹生成` 子节点选择 `生成分段连续路径`。算法在线程池的 `ContinuousPathTask` 中执行，输入为 `NodeCloudData::sprayPath` 和直参考轴。

路径规划页 `btn2` 参数窗口中的 `连续执行` 分组包含：

- `关节6单段最大转角`：默认且最大为 180 度，可向下调整。
- `最大层间连接距离`：默认 `0.015m`，超过后连接线标红。
- `切片执行顺序`：切片号升序或降序。

`连续路径最小点间距` 默认 `0.0001m`、`自动反转开口层` 默认开启，二者作为内部算法参数，不再显示在操作窗口中。

任务处理过程：

1. 按 `SliceIndex` 排列喷杆路径层，并按参数决定升序或降序。
2. 闭合层从最靠近上一层终点的位置开始；开口层可自动反向。
3. 在直参考轴局部坐标系计算连续展开的周向角。
4. 按累计周向转动量拆分，每段不超过配置值且绝不超过 180 度；跨越边界时插入精确边界点。
5. 每个同层分割处写入关节 6 复位标记，相邻层之间单独生成过渡线并检查距离。
6. 主日志输出执行段数、复位点数、处理长度、层间移动长度、最大点间距和异常连接数。

入口：

- `MainWindow::onRequestContinuousPath(...)`
- `MainOpengl::requestContinuousPath(...)`
- `PointDeal::requestContinuousPath(...)`
- `ContinuousPathTask`

重要限制：局部残腔周向角只是当前阶段对关节 6 转角的保守几何代理，不等于机械臂真实关节角。后续必须先生成完整喷杆位姿并做机械臂逆解，再逐点验证实际关节 6 角度。复位标记目前只表达“此处必须中断并复位”，尚未生成退刀、回绕、重新接近等动作。

## 喷嘴离线几何位姿

完成分段连续路径后，右键同一 `轨迹生成` 子节点选择 `生成喷嘴位姿`。算法在线程池的 `NozzlePoseTask` 中执行。

入口：

- `MainWindow::onRequestNozzlePoses(...)`
- `MainOpengl::requestNozzlePoses(...)`
- `PointDeal::requestNozzlePoses(...)`
- `NozzlePoseTask`

当前处理过程：

1. 只读取带 `ClosedLayer` 的闭合拟合轮廓，开口层跳过。
2. 通过 `rotationStartMarkers` 的 `SliceIndex` 找到每层洋红色共同起点，并以该方向为零度。
3. 将轮廓中心投影到有限蓝色安全轴段，得到该层 TCP 位置。
4. 从 TCP 向每个周向角发射射线，与真实拟合轮廓求最近正向交点，得到喷嘴指向；内部采样步长固定为 `5°`。
5. 定义几何工具坐标：局部 `+Z` 为喷嘴朝向，局部 `+X` 为蓝轴方向，局部 `+Y` 保持右手系，并输出 `QuaternionXYZW`。
6. 每层依次写入 `左转处理(0→180°)`、`断能回零(180→0°)`、`右转处理(0→-180°)`、`断能回零(-180→0°)`；层间移动写为 `MotionPhase=4` 且 `PlasmaEnabled=0`。
7. 另生成四个唯一方向的稀疏箭头；`+180/-180°` 在空间中重合，合并为一支浅蓝箭头，避免颜色重叠和遮挡术区。

`MotionPhase` 含义：

- `0`：左半圈处理，等离子开启。
- `1`：左半圈结束后回零，等离子关闭。
- `2`：右半圈处理，等离子开启。
- `3`：右半圈结束后回零，等离子关闭。
- `4`：层间移动到下一层零度 TCP，等离子关闭。

重要限制：这里的 `Joint6GeometricDeg` 是绕残腔蓝轴的几何角，不是机械臂逆解得到的真实关节 6 角度。断能回零当前只描述原位转回零度，没有生成径向退刀、避障回绕或重新接近路径。四元数位于当前模型坐标系且使用临时几何工具轴约定；在手眼标定和真实 TCP 坐标约定完成前不能下发机械臂。

## ROS Launch 与系统自检

ROS launch 管理：

- `src/plasma_gui/src/gui/panel/left_panel/step_wizard/ros_launch_manager/ros_launch_manager.*`

`stop()` / `stopAll()` 使用 SIGINT 方式停止进程，且已经避免阻塞 UI 的等待逻辑。

系统自检：

- `SystemCheckManager`
- 入口：`MainWindow::onRequestSystemCheck()`

当前相机日志不再直接刷主日志大段输出，状态和相机日志窗口由状态栏按钮控制。

## 常用构建命令

```bash
colcon build --packages-select plasma_gui
```

当前构建可能出现 Open3D CMake policy 警告，和业务逻辑无关。

## 后续开发注意点

- 不要让 `setCloudCaptureConfirmEnabled(false)` 影响路径规划页的 `btn2`。
- 路径结果应加入 `轨迹生成` 节点，不应直接显示在 `残腔重建` 节点上。
- 轨迹节点默认只显示蓝色直参考轴，红色弯曲中心线由右键菜单控制。
- 若继续提高路径算法精度，应优先验证体素尺寸、mesh 是否闭合、开口边界是否可靠。
- 下一阶段应将 `NodeCloudData::nozzlePoseSequence` 从模型坐标系转换到机械臂基坐标系，接入真实 TCP 工具坐标和机械臂逆解；随后在回零阶段设计安全退刀/回绕/重新接近动作，再完成碰撞、越界、真实关节 6 转角、剂量、速度和功率检查。当前结果不能直接下发机械臂。

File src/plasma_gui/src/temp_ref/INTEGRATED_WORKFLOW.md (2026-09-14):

# 整机流程主任务

更新时间：2026-07-23

## 主目标

当前唯一主线是将已有模块整合成操作者可以顺序完成的一套整机流程：

```text
系统自检
-> 相机采集
-> 残腔重建与术区选择
-> 路径规划
-> 机械臂执行
-> 等离子处理
-> 处理完成/安全复位
```

真实机械臂连接自检和完整手眼坐标变换的软件框架已经完成，L515 暂用手眼矩阵也已接入。当前等待严格矩阵验收和真实等离子喷枪 TCP；在两项标定完成并验收前，只允许坐标预览，不允许自动执行转换后的路径。此前“人工对准入口 + 工具坐标分层 + J6 左右半圈”仍只作为低速断电演示方案，不能替代正式路径执行。

当前优先级：

```text
已接入 L515 暂用手眼矩阵
-> 完成非接触验证/严格验收
-> 确认真实喷枪 TCP与末端 URDF
-> 已知点转换验收
-> 输出入口后的连续 TCP/法兰位姿
-> 输出每个点的运动阶段与喷涂开关
-> 等离子安全联锁
```

范围边界：软件不规划或控制机械臂从初始位置到腔口/喷涂入口的运动。输出路径的第一个点就是入口后的喷涂起始位姿，下游只消费这个点及其后的喷涂轨迹。

目录边界：机械臂手眼工具统一放在 `src/third_party/plasma_robot/tools/eye_hand/`，TF 与坐标转换工具统一放在 `src/third_party/plasma_robot/tools/tf/`。共享消息包 `plasma_robot_interfaces` 保持独立。L515 暂用矩阵已经接入，TF 包已经迁移；严格验收和真实喷枪 TCP 完成前仍不可执行。

## 中断恢复规则

- 本文档记录的是当前最高优先级任务。后续工作因上下文切换、构建失败、程序退出或工具会话结束而中断时，必须从最后一个未完成项继续，不能跳到其他功能。
- 恢复工作时先检查本文档、`HANDOFF.md`、工作区修改、最近构建结果和正在运行的 ROS/GUI 进程。
- 只有经过代码检查、构建和对应级别验证的项目才能标记完成。
- 不得把临时演示动作描述为自动规划轨迹；界面和日志必须明确当前采用人工入口对准和相对分层运动。

## 当前基础

### 相机与点云流程

- 系统自检可以检查并自动启动相机。
- 已有实时点云暂停/恢复、关键帧裁剪和关键帧保存。
- 已有 Mesh 重建、术区选择、中心轴、切片、轮廓、路径和喷嘴离线位姿生成。
- 当前测试轨迹 `重建1路径` 曾生成 6 个闭合层和 893 个离线几何位姿。

### 机械臂

- RealMan ECO65-BI 驱动、`/joint_states`、MoveJ 和工具坐标 MoveL 已接通。
- 系统自检已正式接入 `rm_driver/rm_eco65_driver.launch.py`，同时验证 `/rm_driver` 和实时六关节状态，15 秒超时。
- 正式 GUI 中已完成一次自动启动相机与真实机械臂驱动的完整自检，结果通过；未发送运动命令。
- `plasma_robot_interfaces` 保持独立；`plasma_eye_hand` 和 `plasma_path_transform` 已分别整理到 `tools/eye_hand/` 和 `tools/tf/`。
- GUI 会冻结采集时 `frame_id`、时间戳和六关节状态，并发布相机坐标系路径。
- 转换链固定为 `T_base_gripper(capture) * T_gripper_camera * T_camera_tcp`；缺少手眼矩阵时拒绝转换。
- 默认加载 L515 `f1423110` 的 HORAUD 暂用矩阵；未验收标定只能输出 `execution_permitted=false` 的预览。
- 当前控制器工具系实机确认是 `Arm_Tip`，工具 `+Z` 朝喷嘴尖端方向。
- `ArmRosAdapter` 已封装 MoveJ、工具坐标 MoveL、停止和当前工具系查询。
- `DemoRotationExecutor` 已实现每层：

```text
J6 左转半圈 -> 回入口角 -> J6 右转半圈 -> 回入口角
-> 沿现场验证的工具轴移动到下一层
```

- 速度固定为 5%，任一步失败或超时会发送停止命令。
- 实机已验证单层旋转，以及沿工具 `+Z` 每层 5 mm 的三层演示。
- 临时脚本位于：
  - `src/plasma_gui/scripts/single_layer_rotation_demo.py`
  - `src/plasma_gui/scripts/multi_layer_rotation_demo.py`

### 等离子

- 主窗口已有气体模式、流量、比例、启动/停止、计时和串口控制界面。
- `Serial::setPlasmaControl(...)` 和 `Serial::emergencyStop()` 已存在。
- 当前等离子控制仍是独立手动页面，没有与机械臂运动阶段形成状态机联锁。
- 机械臂演示执行器中的“喷涂开启/关闭”目前仅写日志，真实等离子输出保持关闭。

## 当前结构问题

1. L515 暂用手眼矩阵已加载，但严格离线验收未通过，只能生成不可执行预览。
2. 当前旧 TCP 可能属于旧笔尖，真实等离子喷枪 TCP 尚未确认。
3. 实测标定完成后，尚需核对转换后的 TCP/法兰位姿、运动阶段和喷涂开关是否与规划路径一致。
4. 系统自检已检查相机和机械臂，但还没有正式的等离子串口/控制器健康检查。
5. 等离子开关没有受机械臂执行阶段、故障状态和急停状态完整约束。
6. GUI 内仍有两个同名 `/plasma_gui_node`，会产生 rosout publisher 警告，后续需单独整理命名。

## 实施顺序

### 0. 真实连接与坐标转换基础（已完成）

- [x] 正式机械臂代码统一放置于 `src/third_party/plasma_robot/`，未整体复制旧交接目录。
- [x] GUI 自检自动启动 ECO65 驱动并验证 `/rm_driver` 与实时六关节状态。
- [x] GUI 默认关闭调试跳过；仅 `PLASMA_GUI_DEBUG_MODE=1` 可跳过机械臂检查。
- [x] 新增 C++ 路径消息接口和坐标转换节点，支持采集时关节状态的 KDL 正解。
- [x] GUI 将采集元数据和规划路径完整发布给转换节点。
- [x] 手眼/TCP 缺失或未验收时禁止执行，示例 identity 不可用于实机运动。
- [x] 接口、手眼数据、TF 转换和 GUI 包构建通过；转换包限定结果 `8 tests, 0 errors, 0 failures`。
- [x] 正式 GUI 完整自检通过，窗口正常关闭且无遗留 ROS/设备进程。
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

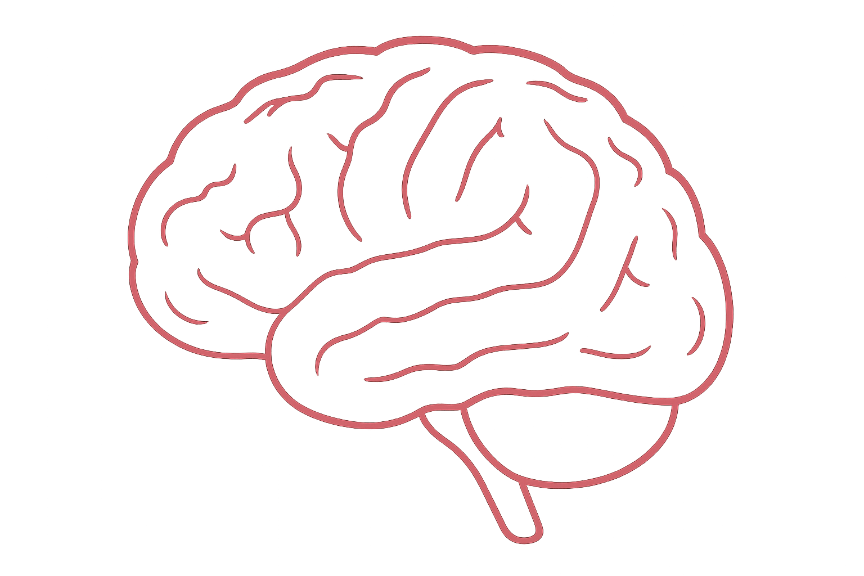
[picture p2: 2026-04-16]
src/plasma_gui/src/image/brain.png

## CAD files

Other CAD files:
src/plasma_gui/src/gui/ui_source/pcd_source/pcd02-1.ply
src/plasma_gui/src/gui/ui_source/rebuild_mesh/关键帧2_mesh_20260716_024209_215.ply
src/plasma_gui/src/gui/ui_source/pcd_source/pcd01.ply
src/plasma_gui/src/gui/ui_source/rebuild_mesh/关键帧4_mesh_20260814_170158_930.ply
src/plasma_gui/src/gui/ui_source/pcd_source/pcd02.ply
src/plasma_gui/src/gui/ui_source/rebuild_mesh/关键帧4_mesh_20260725_004314_331.ply
src/plasma_gui/src/gui/ui_source/pcd_source/pcd03.ply
src/plasma_gui/src/gui/ui_source/rebuild_mesh/关键帧4_mesh_20260726_145957_694.ply
src/plasma_gui/src/gui/ui_source/pcd_source/pcd04.ply
src/plasma_gui/src/gui/ui_source/rebuild_mesh/关键帧2_mesh_20260716_025309_384.ply
src/plasma_gui/src/gui/ui_source/rebuild_mesh/关键帧4_mesh_20260730_181753_018.ply
src/plasma_gui/src/gui/ui_source/rebuild_mesh/关键帧4_mesh_20260729_211632_792.ply
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

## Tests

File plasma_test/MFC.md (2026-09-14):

# STM32F407 双路 MFC 模拟量控制与反馈模块设计说明

> 当前 `plasma_test` 工程已经把旧命名 `MFC1/MFC2` 业务化为 `Ar_MFC/He_MFC`：  
> `Ar_MFC` 对应 PC2/SWRAY1、PA4、PB0，满量程 10 L/min，当前因硬件接线问题禁用；  
> `He_MFC` 对应 PC3/SWRAY2、PA5、PB1，满量程 30 L/min，当前有效。  
> 当前联调和测试命令请优先查看 `MFC模块配置与测试说明.md` 和 `当前代码引脚分配与项目背景.md`；本文主体保留了早期 MFC1/MFC2 设计资料，作为实现依据和历史记录。

## 1. 文档目的

本文档用于指导编程助手为 STM32F407VGT6 控制板实现双路 MFC（Mass Flow Controller，质量流量控制器）的底层驱动与业务接口。

系统中的两路 MFC 均采用模拟量接口：

- 流量设定输入：`0~5 V`
- 流量反馈输出：`0~5 V`
- 两路 MFC 的满量程流量可能不同
- 软件必须通过每个通道独立的 `full_scale_flow_lpm` 字段自动完成流量、电压、DAC 码值和 ADC 反馈之间的换算

示例：

- MFC1：`0~30 L/min`
- MFC2：`0~10 L/min`

软件不应将 `30 L/min` 写死，而应依据通道配置自动计算。

---

## 2. 硬件通道映射

| MFC 通道 | STM32 DAC 引脚 | 外部设定信号 | STM32 ADC 引脚 | 外部反馈信号 |
|---|---|---|---|---|
| MFC1 | PA4 / DAC_OUT1 | FMC_DAC1 | PB0 / ADC12_IN8 | FMC_adc1 |
| MFC2 | PA5 / DAC_OUT2 | FMC_DAC2 | PB1 / ADC12_IN9 | FMC_adc2 |

### 2.1 DAC 输出链路

```text
STM32 DAC
PA4 / PA5
    ↓ 0~约2.5 V
外部运放同相放大 2 倍
    ↓ 0~约5 V
FMC_DAC1 / FMC_DAC2
    ↓
MFC 模拟量设定输入
```

外部运放增益：

```text
Gain = 1 + Rf / Rg
     = 1 + 1k / 1k
     = 2
```

因此：

```text
MFC_SetVoltage = MCU_DAC_Voltage × 2
```

### 2.2 ADC 反馈链路

```text
MFC 模拟量反馈输出
    ↓ 0~5 V
FMC_adc1 / FMC_adc2
    ↓ 10k / 10k 分压
运放缓冲
    ↓ 0~2.5 V
PB0 / PB1 ADC 输入
```

分压比例：

```text
MCU_ADC_PinVoltage = MFC_FeedbackVoltage / 2
```

因此：

```text
MFC_FeedbackVoltage = MCU_ADC_PinVoltage × 2
```

---

## 3. MFC 线性换算关系

每个 MFC 都满足：

```text
0 V                    → 0 L/min
5 V                    → full_scale_flow_lpm
中间范围按线性比例换算
```

其中：

```c
full_scale_flow_lpm
```

表示该通道 MFC 的满量程流量，单位为 `L/min`。

例如：

```c
MFC1.full_scale_flow_lpm = 30.0f;
MFC2.full_scale_flow_lpm = 10.0f;
```

### 3.1 流量转 MFC 设定电压

```text
MFC_SetVoltage =
    TargetFlow / full_scale_flow_lpm × 5.0 V
```

### 3.2 MFC 反馈电压转流量

```text
FeedbackFlow =
    MFC_FeedbackVoltage / 5.0 V × full_scale_flow_lpm
```

### 3.3 示例

若 MFC1 满量程为 `30 L/min`：

| 流量 | 模拟量 |
|---:|---:|
| 0 L/min | 0 V |
| 6 L/min | 1 V |
| 15 L/min | 2.5 V |
| 24 L/min | 4 V |
| 30 L/min | 5 V |

若 MFC2 满量程为 `10 L/min`：

| 流量 | 模拟量 |
|---:|---:|
| 0 L/min | 0 V |
| 2 L/min | 1 V |
| 5 L/min | 2.5 V |
| 8 L/min | 4 V |
| 10 L/min | 5 V |

---

## 4. DAC 设定换算

### 4.1 DAC 电压关系

外部电路放大 2 倍，所以 MCU DAC 实际需要输出：

```text
MCU_DAC_Voltage = MFC_SetVoltage / 2
```

结合流量：

```text
MCU_DAC_Voltage =
    TargetFlow / full_scale_flow_lpm × 5.0 V / 2
```

即：

```text
MCU_DAC_Voltage =
    TargetFlow / full_scale_flow_lpm × 2.5 V
```

### 4.2 DAC 码值

STM32F407 内部 DAC 为 12 位：

```text
DAC 范围：0~4095
参考电压：VDDA，典型约 3.3 V
```

DAC 码值：

```text
DAC_Code =
    MCU_DAC_Voltage / VDDA × 4095
```

合并后：

```text
DAC_Code =
    TargetFlow / full_scale_flow_lpm
    × 5.0
    / DAC_ExternalGain
    / VDDA
    × 4095
```

在本板中：

```text
DAC_ExternalGain = 2.0
VDDA ≈ 3.3 V
```

满量程理论 DAC 码值约为：

```text
2.5 / 3.3 × 4095 ≈ 3102
```

因此软件不能把 MFC 满流量直接映射到 `4095`，而应映射到约 `3102`。

---

## 5. ADC 反馈换算

### 5.1 ADC 引脚电压

STM32F407 ADC 为 12 位：

```text
ADC_Raw：0~4095
```

ADC 引脚电压：

```text
MCU_ADC_PinVoltage =
    ADC_Raw / 4095 × VDDA
```

### 5.2 恢复 MFC 反馈电压

由于硬件做了二分压：

```text
MFC_FeedbackVoltage =
    MCU_ADC_PinVoltage × ADC_DividerRestoreGain
```

本板：

```text
ADC_DividerRestoreGain = 2.0
```

### 5.3 恢复实际流量

```text
FeedbackFlow =
    MFC_FeedbackVoltage / 5.0
    × full_scale_flow_lpm
```

合并：

```text
FeedbackFlow =
    ADC_Raw / 4095
    × VDDA
    × ADC_DividerRestoreGain
    / 5.0
    × full_scale_flow_lpm
```

---

## 6. 推荐数据结构

建议使用每通道独立配置结构体。

```c
typedef enum
{
    MFC_CHANNEL_1 = 0,
    MFC_CHANNEL_2,
    MFC_CHANNEL_COUNT
} mfc_channel_t;

typedef struct
{
    /* MFC 规格参数 */
    float full_scale_flow_lpm;       /* MFC 满量程流量，单位 L/min */
    float control_voltage_max_v;     /* 设定输入满量程电压，默认 5.0 V */
    float feedback_voltage_max_v;    /* 反馈输出满量程电压，默认 5.0 V */

    /* 控制板模拟链路参数 */
    float dac_external_gain;         /* DAC 外部放大倍数，本板为 2.0 */
    float adc_restore_gain;          /* ADC 分压恢复倍数，本板为 2.0 */
    float vdda_v;                     /* ADC/DAC 参考电压，初始可设 3.3 V */

    /* 标定参数 */
    float dac_gain_cal;
    float dac_offset_cal;
    float adc_gain_cal;
    float adc_offset_cal;

    /* 硬件通道 */
    uint32_t dac_channel;
    uint32_t adc_channel;
} mfc_config_t;

typedef struct
{
    float target_flow_lpm;
    float feedback_flow_lpm;

    float target_voltage_v;
    float feedback_voltage_v;

    uint16_t dac_code;
    uint16_t adc_raw;

    bool enabled;
    bool tracking_ok;
} mfc_status_t;

typedef struct
{
    mfc_config_t config;
    mfc_status_t status;
} mfc_device_t;
```

---

## 7. 推荐通道配置

以下数值仅为示例。实际项目中只需要修改 `full_scale_flow_lpm`。

```c
static mfc_device_t g_mfc[MFC_CHANNEL_COUNT] =
{
    [MFC_CHANNEL_1] =
    {
        .config =
        {
            .full_scale_flow_lpm    = 30.0f,
            .control_voltage_max_v  = 5.0f,
            .feedback_voltage_max_v = 5.0f,

            .dac_external_gain      = 2.0f,
            .adc_restore_gain       = 2.0f,
            .vdda_v                 = 3.3f,

            .dac_gain_cal           = 1.0f,
            .dac_offset_cal         = 0.0f,
            .adc_gain_cal           = 1.0f,
            .adc_offset_cal         = 0.0f,

            .dac_channel            = DAC_CHANNEL_1,
            .adc_channel            = ADC_CHANNEL_8
        }
    },

    [MFC_CHANNEL_2] =
    {
        .config =
        {
            .full_scale_flow_lpm    = 10.0f,
            .control_voltage_max_v  = 5.0f,
            .feedback_voltage_max_v = 5.0f,

            .dac_external_gain      = 2.0f,
            .adc_restore_gain       = 2.0f,
            .vdda_v                 = 3.3f,

            .dac_gain_cal           = 1.0f,
            .dac_offset_cal         = 0.0f,
            .adc_gain_cal           = 1.0f,
            .adc_offset_cal         = 0.0f,

            .dac_channel            = DAC_CHANNEL_2,
            .adc_channel            = ADC_CHANNEL_9
        }
    }
};
```

---

## 8. 核心换算函数

### 8.1 流量转 DAC 码值

```c
#include <stdbool.h>
#include <stdint.h>

#define MFC_DAC_FULL_SCALE_CODE  4095.0f

static float MFC_ClampFloat(float value, float min_value, float max_value)
{
    if (value < min_value)
    {
        return min_value;
    }

    if (value > max_value)
    {
        return max_value;
    }

    return value;
}

static uint16_t MFC_FlowToDacCode(const mfc_config_t *config,
                                  float target_flow_lpm)
{
    if ((config == NULL) ||
        (config->full_scale_flow_lpm <= 0.0f) ||
        (config->control_voltage_max_v <= 0.0f) ||
        (config->dac_external_gain <= 0.0f) ||
        (config->vdda_v <= 0.0f))
    {
        return 0U;
    }

    target_flow_lpm = MFC_ClampFloat(
        target_flow_lpm,
        0.0f,
        config->full_scale_flow_lpm
    );

    float mfc_voltage_v =
        target_flow_lpm
        / config->full_scale_flow_lpm
        * config->control_voltage_max_v;

    float mcu_dac_voltage_v =
        mfc_voltage_v / config->dac_external_gain;

    float raw_code =
        mcu_dac_voltage_v
        / config->vdda_v
        * MFC_DAC_FULL_SCALE_CODE;

    raw_code =
        raw_code * config->dac_gain_cal
        + config->dac_offset_cal;

    raw_code = MFC_ClampFloat(
        raw_code,
        0.0f,
        MFC_DAC_FULL_SCALE_CODE
    );

    return (uint16_t)(raw_code + 0.5f);
}
```

### 8.2 ADC 原始值转反馈流量

```c
#define MFC_ADC_FULL_SCALE_CODE  4095.0f

static float MFC_AdcCodeToFlow(const mfc_config_t *config,
                               uint16_t adc_raw)
{
    if ((config == NULL) ||
        (config->full_scale_flow_lpm <= 0.0f) ||
        (config->feedback_voltage_max_v <= 0.0f) ||
        (config->adc_restore_gain <= 0.0f) ||
        (config->vdda_v <= 0.0f))
    {
        return 0.0f;
    }

    float adc_pin_voltage_v =
        (float)adc_raw
        / MFC_ADC_FULL_SCALE_CODE
        * config->vdda_v;

    float feedback_voltage_v =
        adc_pin_voltage_v
        * config->adc_restore_gain;

    feedback_voltage_v =
        feedback_voltage_v
        * config->adc_gain_cal
        + config->adc_offset_cal;

    float flow_lpm =
        feedback_voltage_v
        / config->feedback_voltage_max_v
        * config->full_scale_flow_lpm;

    return MFC_ClampFloat(
        flow_lpm,
        0.0f,
        config->full_scale_flow_lpm
    );
}
```

---

## 9. 对外接口设计

建议 `bsp_mfc.h` 提供以下接口：

```c
#ifndef BSP_MFC_H
#define BSP_MFC_H

#include <stdbool.h>
#include <stdint.h>

typedef enum
{
    MFC_CHANNEL_1 = 0,
    MFC_CHANNEL_2,
    MFC_CHANNEL_COUNT
} mfc_channel_t;

bool MFC_Init(void);

bool MFC_SetFullScaleFlow(mfc_channel_t channel,
                          float full_scale_flow_lpm);

float MFC_GetFullScaleFlow(mfc_channel_t channel);

bool MFC_SetFlow(mfc_channel_t channel,
                 float target_flow_lpm);

float MFC_GetTargetFlow(mfc_channel_t channel);

bool MFC_UpdateFeedback(mfc_channel_t channel);

float MFC_GetFeedbackFlow(mfc_channel_t channel);

uint16_t MFC_GetAdcRaw(mfc_channel_t channel);

uint16_t MFC_GetDacCode(mfc_channel_t channel);

bool MFC_IsTrackingNormal(mfc_channel_t channel);

#endif
```

---

## 10. 设置目标流量

```c
bool MFC_SetFlow(mfc_channel_t channel,
                 float target_flow_lpm)
{
    if (channel >= MFC_CHANNEL_COUNT)
    {
        return false;
    }

    mfc_device_t *device = &g_mfc[channel];

    if (device->config.full_scale_flow_lpm <= 0.0f)
    {
        return false;
    }

    target_flow_lpm = MFC_ClampFloat(
        target_flow_lpm,
        0.0f,
        device->config.full_scale_flow_lpm
    );

    uint16_t dac_code =
        MFC_FlowToDacCode(
            &device->config,
            target_flow_lpm
        );

    if (HAL_DAC_SetValue(
            &hdac,
            device->config.dac_channel,
            DAC_ALIGN_12B_R,
            dac_code) != HAL_OK)
    {
        return false;
    }

    device->status.target_flow_lpm = target_flow_lpm;
    device->status.dac_code = dac_code;

    device->status.target_voltage_v =
        target_flow_lpm
        / device->config.full_scale_flow_lpm
        * device->config.control_voltage_max_v;

    return true;
}
```

---

## 11. 更新反馈流量

ADC 读取函数可以根据工程结构采用轮询、DMA 或中断方式。

```c
bool MFC_UpdateFeedback(mfc_channel_t channel)
{
    if (channel >= MFC_CHANNEL_COUNT)
    {
        return false;
    }

    mfc_device_t *device = &g_mfc[channel];

    uint16_t adc_raw = BSP_ADC_ReadChannel(
        device->config.adc_channel
    );

    float feedback_flow_lpm =
        MFC_AdcCodeToFlow(
            &device->config,
            adc_raw
        );

    float adc_pin_voltage_v =
        (float)adc_raw
        / 4095.0f
        * device->config.vdda_v;

    float feedback_voltage_v =
        adc_pin_voltage_v
        * device->config.adc_restore_gain;

    device->status.adc_raw = adc_raw;
    device->status.feedback_voltage_v = feedback_voltage_v;
    device->status.feedback_flow_lpm = feedback_flow_lpm;

    return true;
}
```

---

## 12. 满量程字段自动计算示例

### 12.1 MFC1：30 L/min

```c
g_mfc[MFC_CHANNEL_1].config.full_scale_flow_lpm = 30.0f;

MFC_SetFlow(MFC_CHANNEL_1, 15.0f);
```

自动计算：

```text
目标比例 = 15 / 30 = 50%
MFC 设定电压 = 5 × 50% = 2.5 V
MCU DAC 电压 = 2.5 / 2 = 1.25 V
DAC 码值约 = 1.25 / 3.3 × 4095 ≈ 1551
```

### 12.2 MFC2：10 L/min

```c
g_mfc[MFC_CHANNEL_2].config.full_scale_flow_lpm = 10.0f;

MFC_SetFlow(MFC_CHANNEL_2, 5.0f);
```

自动计算：

```text
目标比例 = 5 / 10 = 50%
MFC 设定电压 = 5 × 50% = 2.5 V
MCU DAC 电压 = 2.5 / 2 = 1.25 V
DAC 码值约 = 1551
```

可以看到，虽然两台 MFC 的满量程不同，但只要目标流量占满量程的比例相同，最终模拟设定电压相同。

---

## 13. 运行时修改满量程

软件应允许修改某个通道的满量程：

```c
bool MFC_SetFullScaleFlow(mfc_channel_t channel,
                          float full_scale_flow_lpm)
{
    if ((channel >= MFC_CHANNEL_COUNT) ||
        (full_scale_flow_lpm <= 0.0f))
    {
        return false;
    }

    g_mfc[channel].config.full_scale_flow_lpm =
        full_scale_flow_lpm;

    /*
     * 满量程修改后，建议重新下发当前目标流量，
     * 避免旧 DAC 码值仍对应之前的比例。
     */
    return MFC_SetFlow(
        channel,
        g_mfc[channel].status.target_flow_lpm
    );
}
```

如果 MFC 型号固定，也可以把满量程写在编译期配置表中，不开放运行时修改。

---

## 14. 反馈异常检测

系统同时具备设定值和反馈值，可以判断 MFC 是否正常跟踪目标流量。

建议不要仅使用固定误差，而是采用：

```text
允许误差 =
    max(固定误差, 满量程百分比误差)
```

例如：

```c
static bool MFC_CheckTracking(const mfc_device_t *device)
{
    const float absolute_tolerance_lpm = 0.5f;
    const float relative_tolerance = 0.05f;

    float relative_error_lpm =
        device->config.full_scale_flow_lpm
        * relative_tolerance;

    float allowed_error_lpm =
        (relative_error_lpm > absolute_tolerance_lpm)
        ? relative_error_lpm
        : absolute_tolerance_lpm;

    float error_lpm =
        device->status.target_flow_lpm
        - device->status.feedback_flow_lpm;

    if (error_lpm < 0.0f)
    {
        error_lpm = -error_lpm;
    }

    return error_lpm <= allowed_error_lpm;
}
```

还应加入：

- MFC 上电等待时间
- 流量建立延时
- 连续异常计数
- 零流量死区
- 反馈断线判断
- 反馈超量程判断
- 气源不足判断
- MFC 未上电判断

---

## 15. 推荐滤波

MFC 模拟反馈可能存在噪声，建议先做均值滤波或一阶低通滤波。

### 15.1 简单一阶滤波

```c
static float MFC_LowPassFilter(float previous,
                               float current,
                               float alpha)
{
    if (alpha < 0.0f)
    {
        alpha = 0.0f;
    }

    if (alpha > 1.0f)
    {
        alpha = 1.0f;
    }

    return previous
        + alpha * (current - previous);
}
```

示例：

```c
filtered_flow =
    MFC_LowPassFilter(
        filtered_flow,
        current_flow,
        0.1f
    );
```

---

## 16. 标定建议

理论值会受到以下因素影响：

- VDDA 实际电压
- 分压电阻误差
- 运放增益误差
- 运放输出摆幅
- 运放零点偏移
- MFC 零点和满量程误差
- 地线压降
- 接口负载

建议每个通道分别进行标定。

### 16.1 DAC 标定

依次设置：

```text
0%
20%
40%
60%
80%
100%
```

例如对 30 L/min MFC：

```text
0、6、12、18、24、30 L/min
```

测量 `FMC_DACx` 实际输出电压，拟合：

```text
实际输出码值 =
    理论码值 × dac_gain_cal
    + dac_offset_cal
```

### 16.2 ADC 标定

向 `FMC_adcx` 输入：

```text
0 V、1 V、2 V、3 V、4 V、5 V
```

记录 ADC 原始值并拟合：

```text
实际反馈电压 =
    理论反馈电压 × adc_gain_cal
    + adc_offset_cal
```

---

## 17. CubeMX 配置要求

### 17.1 DAC

```text
PA4 → DAC_OUT1
PA5 → DAC_OUT2
```

配置：

```text
DAC Channel 1：Enable
DAC Channel 2：Enable
Output Buffer：按实际测试决定，通常可先 Enable
Trigger：None
```

程序启动：

```c
HAL_DAC_Start(&hdac, DAC_CHANNEL_1);
HAL_DAC_Start(&hdac, DAC_CHANNEL_2);

MFC_SetFlow(MFC_CHANNEL_1, 0.0f);
MFC_SetFlow(MFC_CHANNEL_2, 0.0f);
```

### 17.2 ADC

```text
PB0 → ADC12_IN8
PB1 → ADC12_IN9
```

可以使用：

- ADC1 扫描两通道
- DMA 循环采样
- 定时器触发
- 软件定时读取

建议初始采用：

```text
ADC1
Scan Conversion Mode：Enable
Continuous Conversion：Enable
DMA Continuous Requests：Enable
通道：IN8、IN9
采样时间：较长采样周期，例如 84 或 144 cycles
```

较长采样时间有利于降低模拟前端源阻抗和滤波电容对采样稳定性的影响。

---

## 18. 安全要求

### 18.1 上电默认零流量

初始化 DAC 后立即设置：

```c
MFC_SetFlow(MFC_CHANNEL_1, 0.0f);
MFC_SetFlow(MFC_CHANNEL_2, 0.0f);
```

### 18.2 参数限制

所有目标流量必须限制在：

```text
0 ≤ target_flow_lpm ≤ full_scale_flow_lpm
```

### 18.3 配置有效性检查

以下配置必须大于零：

```text
full_scale_flow_lpm
control_voltage_max_v
feedback_voltage_max_v
dac_external_gain
adc_restore_gain
vdda_v
```

### 18.4 MFC 模拟地

必须确保：

```text
MFC Signal GND
    ↔
控制板模拟地/系统地
```

否则模拟量没有共同参考，可能导致控制误差、反馈漂移或接口异常。

---

## 19. 推荐文件结构

```text
BSP/
├── bsp_mfc.h
├── bsp_mfc.c
├── bsp_adc.h
├── bsp_adc.c
├── bsp_dac.h
└── bsp_dac.c
```

职责建议：

```text
bsp_adc：
    ADC 初始化后的通道读取
    DMA 数据管理
    原始值获取

bsp_dac：
    DAC 启动
    原始码值设置

bsp_mfc：
    MFC 规格配置
    满量程字段管理
    流量与电压换算
    DAC 设定
    ADC 反馈换算
    滤波
    状态与异常检测
```

---

## 20. 分层硬件配置方案

为了避免将 PCB 参数、MFC 型号参数和生产标定参数混在一起，配置应拆分为三层：

1. **MFC 设备规格配置**：描述外部 MFC 的流量范围和模拟接口范围。
2. **板卡模拟硬件配置**：描述 DAC 放大、ADC 分压、参考电压和安全上限。
3. **标定与诊断配置**：描述每路实际标定结果和异常判断参数。

### 20.1 MFC 设备规格配置

```c
typedef struct
{
    float flow_min_lpm;              /* 最小流量，通常为 0 L/min */
    float flow_max_lpm;              /* MFC 满量程流量 */

    float set_voltage_min_v;         /* MFC 设定输入最小电压 */
    float set_voltage_max_v;         /* MFC 设定输入最大电压 */

    float feedback_voltage_min_v;    /* MFC 反馈输出最小电压 */
    float feedback_voltage_max_v;    /* MFC 反馈输出最大电压 */
} mfc_device_spec_t;
```

当前项目典型配置：

```text
MFC1：0~30 L/min，设定 0~5 V，反馈 0~5 V
MFC2：0~10 L/min，设定 0~5 V，反馈 0~5 V
```

这样不仅支持两路满量程不同，也能扩展到：

```text
1~5 V 对应 0~30 L/min
0~10 V 对应 0~100 L/min
```

换算函数不得假定接口一定是 `0~5 V`。

### 20.2 DAC 板卡硬件配置

该结构描述 STM32 DAC 到 MFC 设定输入之间的模拟链路。

```c
typedef struct
{
    float vref_v;                    /* DAC 参考电压，通常为 VDDA */
    uint16_t resolution_max;         /* 12 位 DAC 为 4095 */

    float interface_output_min_v;    /* 板卡 FMC_DACx 接口最小输出 */
    float interface_output_max_v;    /* 板卡 FMC_DACx 接口最大输出 */

    float external_gain;             /* 外部运放增益，本板理论为 2.0 */
    float external_offset_v;         /* 外部模拟链路偏置，本板理论为 0 */

    float mcu_dac_min_v;              /* PA4/PA5 允许使用的最小目标电压 */
    float mcu_dac_max_v;              /* PA4/PA5 允许使用的最大目标电压 */

    uint32_t hal_dac_channel;
} mfc_dac_hw_config_t;
```

本板理论配置：

```c
.vref_v                = 3.3f,
.resolution_max         = 4095U,

.interface_output_min_v = 0.0f,
.interface_output_max_v = 5.0f,

.external_gain          = 2.0f,
.external_offset_v      = 0.0f,

.mcu_dac_min_v           = 0.0f,
.mcu_dac_max_v           = 2.5f,
```

需要明确区分：

```c
mcu_dac_max_v
```

表示 STM32 的 PA4/PA5 引脚目标电压上限，本板约为 `2.5 V`。

```c
interface_output_max_v
```

表示经过外部运放后，`FMC_DAC1/FMC_DAC2` 接口允许输出的上限，本板为 `5.0 V`。

### 20.3 ADC 板卡硬件配置

该结构描述 MFC 反馈输出到 STM32 ADC 之间的模拟链路。

```c
typedef struct
{
    float vref_v;                    /* ADC 参考电压 */
    uint16_t resolution_max;         /* 12 位 ADC 为 4095 */

    float interface_input_min_v;     /* FMC_adcx 接口最小输入 */
    float interface_input_max_v;     /* FMC_adcx 接口最大输入 */

    float divider_ratio;             /* 外部接口电压到 ADC 引脚的比例 */
    float analog_offset_v;           /* 模拟链路偏置 */

    float mcu_adc_min_v;              /* PB0/PB1 ADC 引脚允许最小电压 */
    float mcu_adc_max_v;              /* PB0/PB1 ADC 引脚允许最大电压 */

    uint32_t hal_adc_channel;
} mfc_adc_hw_config_t;
```

本板 `10 kΩ + 10 kΩ` 分压配置：

```c
.vref_v                = 3.3f,
.resolution_max         = 4095U,

.interface_input_min_v  = 0.0f,
.interface_input_max_v  = 5.0f,

.divider_ratio          = 0.5f,
.analog_offset_v        = 0.0f,

.mcu_adc_min_v           = 0.0f,
.mcu_adc_max_v           = 2.5f,
```

其中：

```text
ADC 引脚电压 = 外部反馈电压 × divider_ratio
外部反馈电压 = ADC 引脚电压 / divider_ratio
```

推荐使用 `divider_ratio = 0.5f` 直接描述硬件，不再将 `adc_restore_gain = 2.0f` 作为唯一核心字段，以避免方向混淆。

### 20.4 标定配置

```c
typedef struct
{
    float dac_gain;                  /* DAC 码值增益修正，默认 1 */
    float dac_offset_code;           /* DAC 码值偏置修正，默认 0 */

    float adc_gain;                  /* ADC 恢复电压增益修正，默认 1 */
    float adc_offset_v;              /* ADC 恢复电压偏置修正，默认 0 */
} mfc_calibration_t;
```

建议标定参数按通道独立保存，并可存储到内部 Flash 参数区。

### 20.5 诊断配置

```c
typedef struct
{
    float tracking_abs_tolerance_lpm; /* 绝对跟踪误差 */
    float tracking_relative_tolerance;/* 满量程百分比误差 */
    float zero_deadband_lpm;           /* 零点死区 */
    uint32_t response_timeout_ms;      /* 流量建立超时 */
} mfc_diagnostic_config_t;
```

### 20.6 完整通道配置结构

```c
typedef struct
{
    mfc_device_spec_t device;
    mfc_dac_hw_config_t dac_hw;
    mfc_adc_hw_config_t adc_hw;
    mfc_calibration_t calibration;
    mfc_diagnostic_config_t diagnostics;
} mfc_channel_config_t;

typedef struct
{
    const char *name;
    mfc_channel_config_t config;
    mfc_status_t status;
} mfc_device_t;
```

---

## 21. 推荐完整通道配置示例

```c
static mfc_device_t g_mfc[MFC_CHANNEL_COUNT] =
{
    [MFC_CHANNEL_1] =
    {
        .name = "Helium MFC",
        .config =
        {
            .device =
            {
                .flow_min_lpm           = 0.0f,
                .flow_max_lpm           = 30.0f,
                .set_voltage_min_v       = 0.0f,
                .set_voltage_max_v       = 5.0f,
                .feedback_voltage_min_v  = 0.0f,
                .feedback_voltage_max_v  = 5.0f
            },

            .dac_hw =
            {
                .vref_v                 = 3.3f,
                .resolution_max          = 4095U,
                .interface_output_min_v  = 0.0f,
                .interface_output_max_v  = 5.0f,
                .external_gain           = 2.0f,
                .external_offset_v       = 0.0f,
                .mcu_dac_min_v            = 0.0f,
                .mcu_dac_max_v            = 2.5f,
                .hal_dac_channel         = DAC_CHANNEL_1
            },

            .adc_hw =
            {
                .vref_v                 = 3.3f,
                .resolution_max          = 4095U,
                .interface_input_min_v   = 0.0f,
                .interface_input_max_v   = 5.0f,
                .divider_ratio           = 0.5f,
                .analog_offset_v         = 0.0f,
                .mcu_adc_min_v            = 0.0f,
                .mcu_adc_max_v            = 2.5f,
                .hal_adc_channel         = ADC_CHANNEL_8
            },

            .calibration =
            {
                .dac_gain               = 1.0f,
                .dac_offset_code        = 0.0f,
                .adc_gain               = 1.0f,
                .adc_offset_v           = 0.0f
            },

            .diagnostics =
            {
                .tracking_abs_tolerance_lpm = 0.5f,
                .tracking_relative_tolerance = 0.05f,
                .zero_deadband_lpm           = 0.2f,
                .response_timeout_ms         = 2000U
            }
        }
    },

    [MFC_CHANNEL_2] =
    {
        .name = "Argon MFC",
        .config =
        {
            .device =
            {
                .flow_min_lpm           = 0.0f,
                .flow_max_lpm           = 10.0f,
                .set_voltage_min_v       = 0.0f,
                .set_voltage_max_v       = 5.0f,
                .feedback_voltage_min_v  = 0.0f,
                .feedback_voltage_max_v  = 5.0f
            },

            .dac_hw =
            {
                .vref_v                 = 3.3f,
                .resolution_max          = 4095U,
                .interface_output_min_v  = 0.0f,
                .interface_output_max_v  = 5.0f,
                .external_gain           = 2.0f,
                .external_offset_v       = 0.0f,
                .mcu_dac_min_v            = 0.0f,
                .mcu_dac_max_v            = 2.5f,
                .hal_dac_channel         = DAC_CHANNEL_2
            },

            .adc_hw =
            {
                .vref_v                 = 3.3f,
                .resolution_max          = 4095U,
                .interface_input_min_v   = 0.0f,
                .interface_input_max_v   = 5.0f,
                .divider_ratio           = 0.5f,
                .analog_offset_v         = 0.0f,
                .mcu_adc_min_v            = 0.0f,
                .mcu_adc_max_v            = 2.5f,
                .hal_adc_channel         = ADC_CHANNEL_9
            },

            .calibration =
            {
                .dac_gain               = 1.0f,
                .dac_offset_code        = 0.0f,
                .adc_gain               = 1.0f,
                .adc_offset_v           = 0.0f
            },

            .diagnostics =
            {
                .tracking_abs_tolerance_lpm = 0.3f,
                .tracking_relative_tolerance = 0.05f,
                .zero_deadband_lpm           = 0.1f,
                .response_timeout_ms         = 2000U
            }
        }
    }
};
```

---

## 22. 基于完整配置的统一换算
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

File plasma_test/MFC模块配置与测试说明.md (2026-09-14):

# MFC 模块配置与测试说明

## 1. 当前接入状态

当前 MFC 相关代码只放在两个文件中：

```text
plasma_test/Inc/mfc.h
plasma_test/Src/mfc.c
```

当前硬件通道状态：

| 通道 | 电源继电器 | DAC 设定 | ADC 反馈 | 当前状态 |
|---|---|---|---|---|
| Ar_MFC | PC2 / SWRAY1 | PA4 / DAC_OUT1 / FMC_DAC1 | PB0 / ADC12_IN8 / FMC_adc1 | 禁用，满量程 10 L/min |
| He_MFC | PC3 / SWRAY2 | PA5 / DAC_OUT2 / FMC_DAC2 | PB1 / ADC12_IN9 / FMC_adc2 | 有效，满量程 30 L/min |

Ar_MFC 当前因 PC2/SWRAY1 硬件接线问题暂时禁用。即使发送 Ar_MFC 上电命令，PC2 也不会吸合；`ar_valve` 仍可单独测试。

## 2. 最常修改的参数

配置位于 `plasma_test/Src/mfc.c` 的 `g_mfc[]` 数组。

最常改的是每个 MFC 的满量程：

```c
.flow_max_lpm = 10.0f
```

含义是该 MFC 的满量程流量，单位 `L/min`。

示例：

```text
10 L/min 的 MFC：flow_max_lpm = 10.0f
30 L/min 的 MFC：flow_max_lpm = 30.0f
```

软件不会把 10 或 30 写死在公式里，而是根据每路通道自己的 `flow_max_lpm` 自动计算 DAC 和反馈流量。

## 3. 关键模拟量参数

MFC 设定输入是 `0-5 V`，但 STM32 DAC 不是直接输出 5 V。本板 DAC 后面有 2 倍运放：

```text
MCU DAC 输出 0-2.5 V
外部运放放大 2 倍
MFC 接口得到 0-5 V
```

所以配置里：

```c
.external_gain = 2.0f
.mcu_dac_max_v = 2.5f
.interface_output_max_v = 5.0f
```

这三个不要随便改，除非硬件电路变化。

MFC 反馈输出也是 `0-5 V`，进入 MCU 前经过二分压：

```text
MFC 反馈 0-5 V
10k/10k 分压
MCU ADC 引脚 0-2.5 V
```

所以配置里：

```c
.divider_ratio = 0.5f
.mcu_adc_max_v = 2.5f
.interface_input_max_v = 5.0f
```

## 4. 流量命令单位

串口命令中的 MFC 流量字段单位是 `0.01 L/min`。

```text
100  = 1.00 L/min
500  = 5.00 L/min
1000 = 10.00 L/min
1500 = 15.00 L/min
3000 = 30.00 L/min
```

当前有效通道 He_MFC 使用：

```text
HeFLOWRelay bit 0x10  控制 He_MFC 上电
HeOutValue            设置 He_MFC 目标流量
```

Ar_MFC 当前禁用，对应字段仍保留：

```text
ArFLOWRelay bit 0x10
ArOutValue
```

## 5. 测试命令

### 5.1 He_MFC 上电，流量 0.00 L/min

```text
FF FE 00 00 00 00 10 00 00 00 00 00 0D 02 00 00
```

### 5.2 He_MFC 上电，同时打开氦气电磁阀，1-5 L/min

1.00 L/min：

```text
FF FE 00 00 00 00 11 64 00 00 00 00 72 02 00 00
```

2.00 L/min：

```text
FF FE 00 00 00 00 11 C8 00 00 00 00 D6 02 00 00
```

3.00 L/min：

```text
FF FE 00 00 00 00 11 2C 01 00 00 00 3B 02 00 00
```

4.00 L/min：

```text
FF FE 00 00 00 00 11 90 01 00 00 00 9F 02 00 00
```

5.00 L/min：

```text
FF FE 00 00 00 00 11 F4 01 00 00 00 03 03 00 00
```

### 5.3 He_MFC 只上电并设置 1.00 L/min

```text
FF FE 00 00 00 00 10 64 00 00 00 00 71 02 00 00
```

### 5.4 He_MFC 只上电并设置 5.00 L/min

```text
FF FE 00 00 00 00 10 F4 01 00 00 00 02 03 00 00
```

### 5.5 He_MFC 只上电并设置 10.00 L/min

```text
FF FE 00 00 00 00 10 E8 03 00 00 00 F8 02 00 00
```

### 5.6 He_MFC 只上电并设置 15.00 L/min

```text
FF FE 00 00 00 00 10 DC 05 00 00 00 EE 02 00 00
```

### 5.7 He_MFC 只上电并设置 30.00 L/min

```text
FF FE 00 00 00 00 10 B8 0B 00 00 00 D0 02 00 00
```

### 5.8 He_MFC 设置 15.00 L/min，同时打开氦气电磁阀

```text
FF FE 00 00 00 00 11 DC 05 00 00 00 EF 02 00 00
```

### 5.9 He_MFC 断电并清零

```text
FF FE 00 00 00 00 00 00 00 00 00 00 FD 01 00 00
```

### 5.10 尝试 Ar_MFC 设置 5.00 L/min

Ar_MFC 当前禁用，所以该命令不会吸合 PC2。

```text
FF FE 00 00 00 00 00 00 00 10 F4 01 02 03 00 00
```

### 5.11 尝试 Ar_MFC 设置 10.00 L/min

Ar_MFC 满量程是 10 L/min，但当前通道仍禁用，所以该命令也不会吸合 PC2。

```text
FF FE 00 00 00 00 00 00 00 10 E8 03 F8 02 00 00
```

### 5.12 急停测试用组合命令

除三色灯和蜂鸣器外，继电器、气阀、MFC 供电位和三路风扇全部打开，并把 He/Ar MFC 目标流量设为 1.00 L/min：

```text
FF FE 00 F1 00 00 11 64 00 11 64 00 D8 03 00 00
```

发送后按下硬件急停，应观察到气阀关闭、继电器关闭、MFC 目标流量回到 0.00 L/min；ADC、压力通讯、USART1 日志和 USART6 状态包继续运行。

## 6. 日志观察

发送命令后看串口日志中的 `Gas Path`：

```text
===Gas Path===
  He_MFC : ON  Ar_MFC : DISABLED
  He Valve: ON  Ar Valve: OFF
  He Target  : 5.00 L/min  He DAC Out : 1551
  He Feedback: 4.98 L/min  He ADC Input : 1235
  He Tracking: OK
```

重点看：

| 字段 | 含义 |
|---|---|
| `He_MFC` | 氦气 MFC 电源状态 |
| `Ar_MFC` | 氩气 MFC 电源状态；当前禁用 |
| `He Target` | 软件下发给 He_MFC 的目标流量 |
| `He Feedback` | ADC 反馈换算后的 He_MFC 实际流量 |
| `He DAC Out` | He_MFC 当前 DAC 原始码值 |
| `He ADC Input` | He_MFC 当前 ADC 原始采样值 |
| `He Tracking` | He_MFC 反馈是否跟踪目标 |

## 7. DAC 码值参考

当前 He_MFC 满量程为 `30 L/min`，接口设定为 `0-5 V`，DAC 外部增益为 2。

| 目标流量 | MFC 接口电压 | MCU DAC 电压 | DAC 码值约 |
|---:|---:|---:|---:|
| 0.00 L/min | 0.00 V | 0.00 V | 0 |
| 3.00 L/min | 0.50 V | 0.25 V | 310 |
| 15.00 L/min | 2.50 V | 1.25 V | 1551 |
| 30.00 L/min | 5.00 V | 2.50 V | 3102 |

Ar_MFC 满量程为 `10 L/min`，但当前禁用。后续启用后，设置 `5.00 L/min` 也是 50% 满量程，DAC 码值同样约为 `1551`。

## 8. 改 Ar_MFC 为可用

等 Ar_MFC 硬件修复后，在 `mfc.c` 中把 Ar_MFC 的：

```c
.channel_enable = MFC_CHANNEL_DISABLED
```

改成：

```c
.channel_enable = MFC_CHANNEL_ENABLED
```

然后确认：

```c
.flow_max_lpm
.power_active_level
```

是否和实际 MFC 型号、继电器极性一致。

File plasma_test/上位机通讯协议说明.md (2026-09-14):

# 等离子控制板上位机通讯协议说明

> 本文档面向上位机软件开发，用于实现上位机与 `plasma_test` 下位机固件的通讯。  
> 当前协议以 USART6 / 485-2 / `cmd_uart` 作为正式上位机通讯口；USART1 / `log_uart` 主要用于调试日志。

## 1. 通讯接口

| 项目 | 参数 |
|---|---|
| 正式上位机通讯口 | USART6 / `cmd_uart` |
| 板端接口 | 485-2 / J365 / `485_A_2`、`485_B_2` |
| MCU 引脚 | PC6 = USART6_TX，PC7 = USART6_RX |
| 波特率 | 115200 |
| 数据位 | 8 |
| 校验位 | None |
| 停止位 | 1 |
| 流控 | None |
| 字节序 | 小端 |

USART1 / `log_uart` 也能接收同样的 16 字节控制帧，但它的主要用途是输出 ASCII 状态日志，不建议上位机正式控制使用。

## 2. 通讯流程

推荐上位机启动流程：

1. 打开 USART6 对应串口，配置为 `115200, 8N1`。
2. 发送 `cmd_uart` 握手请求帧。
3. 等待下位机返回 ACK。
4. ACK 正确后，认为板子已连接。
5. 接收下位机每约 `300 ms` 主动上传的 28 字节状态包。
6. 需要控制设备时，发送 16 字节控制命令。
7. 发送命令后，以上传状态包中的实际状态为准，不要只以上位机本地命令缓存为准。

当前没有心跳断线机制。握手成功后，下位机内部会锁存 `cmd_uart` 已连接状态，直到板子复位。

## 3. 握手协议

握手只能通过 USART6 / `cmd_uart` 发送。

上位机发送握手请求：

```text
FF FE C5 A5 A5 5A 3C 3C C3 96 96 69 36 07 00 00
```

下位机返回 ACK：

```text
FF FE CA A5 A5 5A 3C 3C C3 96 96 69 3B 07 00 00
```

握手帧仍然使用 16 字节基础帧格式和校验规则，但下位机在 `cmd_uart` 上识别到该组合后不会进入普通控制逻辑，所以不会动作继电器、气阀、MFC、风扇、蜂鸣器等执行器。

注意：不要把握手请求发到 USART1 / `log_uart`。USART1 会按普通控制帧处理，其中 `EmerStop=C5` 会触发命令急停。

## 4. 基础帧格式

上位机发送的普通控制命令固定为 16 字节。

| 字节位置 | 字段 | 类型 | 字节序 | 说明 |
|---|---|---|---|---|
| 0-1 | `header` | uint16 | 小端 | 固定 `0xFEFF`，发送字节为 `FF FE` |
| 2 | `EmerStop` | uint8 | - | 急停/特殊命令字段 |
| 3 | `VolRelay` | uint8 | - | 电源继电器、调压器继电器、风扇开关位 |
| 4-5 | `VolOutValue` | uint16 | 小端 | 电压/调压器预留设定值；风扇调速帧中为 5V 风扇占空比 |
| 6 | `HeFLOWRelay` | uint8 | - | He_MFC、氦气阀、蜂鸣器位 |
| 7-8 | `HeOutValue` | uint16 | 小端 | He_MFC 目标流量，单位 `0.01 L/min`；风扇调速帧中为 `device_fan` 占空比 |
| 9 | `ArFLOWRelay` | uint8 | - | Ar_MFC、氩气阀、RGB 位 |
| 10-11 | `ArOutValue` | uint16 | 小端 | Ar_MFC 目标流量，单位 `0.01 L/min`；风扇调速帧中为 `ctr_main_fan` 占空比 |
| 12-15 | `footer` | uint32 | 小端 | 前 12 字节逐字节求和 |

## 5. 校验规则

校验值是前 12 个字节的无符号累加和，按 uint32 小端放入字节 12-15。

伪代码：

```c
uint32_t checksum = 0;
for (int i = 0; i < 12; i++) {
    checksum += packet[i];
}
packet[12] = checksum & 0xFF;
packet[13] = (checksum >> 8) & 0xFF;
packet[14] = (checksum >> 16) & 0xFF;
packet[15] = (checksum >> 24) & 0xFF;
```

示例：打开等离子电源继电器。

前 12 字节：

```text
FF FE 00 10 00 00 00 00 00 00 00 00
```

求和为 `0x0000020D`，小端为 `0D 02 00 00`，完整帧：

```text
FF FE 00 10 00 00 00 00 00 00 00 00 0D 02 00 00
```

## 6. 普通控制字段

当 `EmerStop = 0x00` 时，按普通控制帧执行。

### 6.1 `VolRelay`

| 位值 | 名称 | 控制对象 | 说明 |
|---:|---|---|---|
| `0x01` | `RELAY_VOL_MOD_ON` | `vol_mod_relay` | 调压器继电器，PC1 |
| `0x10` | `RELAY_PLASMA_ON` | `plasma_relay` | 等离子电源继电器，PA7 |
| `0x20` | `CTR_ASS_FAN_ON` | `ctr_ass_fan` | 5V 控制辅助风扇，PB5 |
| `0x40` | `DEVICE_FAN_ON` | `device_fan` | 12V 设备风扇，PB6 |
| `0x80` | `CTR_MAIN_FAN_ON` | `ctr_main_fan` | 12V 控制主风扇，PB7 |

普通控制帧中，风扇开关位为 1 时按 100% 占空比输出；为 0 时关闭。需要调速时使用专用风扇调速帧。

### 6.2 `HeFLOWRelay`

| 位值 | 名称 | 控制对象 | 说明 |
|---:|---|---|---|
| `0x01` | `RELAY_GAS_VALVE_ON` | `he_valve` | 氦气电磁阀，PD12，高电平开 |
| `0x02` | `BUZZER_1_ON` | `buzzer_1` | 红色错误蜂鸣器，命令打开为长鸣 |
| `0x04` | `BUZZER_2_ON` | `buzzer_2` | 黄色提醒蜂鸣器，命令打开为长开 |
| `0x10` | `RELAY_FLOW_METER_ON` | `He_MFC` | He_MFC 上电，PC3/SWRAY2 |

`HeOutValue` 是 He_MFC 目标流量，单位为 `0.01 L/min`。

```text
100  -> 1.00 L/min
500  -> 5.00 L/min
1000 -> 10.00 L/min
```

当前 He_MFC 有效，满量程按 30 L/min 配置。

### 6.3 `ArFLOWRelay`

| 位值 | 名称 | 控制对象 | 说明 |
|---:|---|---|---|
| `0x01` | `RELAY_GAS_VALVE_ON` | `ar_valve` | 氩气电磁阀，PD13，高电平开 |
| `0x02` | `RGB_RED_ON` | `rgb_red` | 三色灯红色位，当前会被系统状态灯逻辑覆盖 |
| `0x04` | `RGB_GREEN_ON` | `rgb_green` | 三色灯绿色位，当前会被系统状态灯逻辑覆盖 |
| `0x08` | `RGB_YELLOW_ON` | `rgb_yellow` | 三色灯黄色位，当前会被系统状态灯逻辑覆盖 |
| `0x10` | `RELAY_FLOW_METER_ON` | `Ar_MFC` | Ar_MFC 上电，PC2/SWRAY1 |

`ArOutValue` 是 Ar_MFC 目标流量，单位为 `0.01 L/min`。

当前 Ar_MFC 因硬件接线问题暂时禁用，发送上电和流量设定命令不会吸合 PC2；`ar_valve` 可正常单独控制。

## 7. 特殊命令

### 7.1 命令急停

普通控制帧中，如果 `EmerStop != 0x00` 且 `EmerStop != 0xA5`，下位机会执行命令急停关闭策略。

命令急停会关闭当前已接入的主要输出：

```text
plasma_relay
vol_mod_relay
He_MFC / Ar_MFC 电源
he_valve / ar_valve
ctr_ass_fan / device_fan / ctr_main_fan
buzzer_1 / buzzer_2
rgb_red / rgb_green / rgb_yellow
LED1 / LED2 / LED3
```

示例命令急停帧：

```text
FF FE F8 00 00 00 00 00 00 00 00 00 F5 02 00 00
```

注意：命令急停不同于硬件急停。硬件急停来自 INT3 常闭急停输入，策略见第 10 节。

### 7.2 风扇调速帧

当 `EmerStop = 0xA5` 时，该帧为风扇调速专用帧，只更新三路风扇 PWM。

| 字段 | 含义 |
|---|---|
| `VolRelay` | 三路风扇开关位，仍使用 `0x20/0x40/0x80` |
| `VolOutValue` | `ctr_ass_fan` 占空比，范围 `0-1000` |
| `HeOutValue` | `device_fan` 占空比，范围 `0-1000` |
| `ArOutValue` | `ctr_main_fan` 占空比，范围 `0-1000` |

占空比规则：

```text
0    -> 关闭
500  -> 50%
1000 -> 100%
>1000 会被限制为 1000
如果开关位为 0，则对应风扇占空比强制为 0
如果开关位为 1 且占空比字段为 0，则按 100% 兼容处理
```

示例：三路风扇分别设置为 30%、60%、90%。

```text
FF FE A5 E0 2C 01 00 58 02 00 84 03 90 04 00 00
```

## 8. 下位机状态包

`cmd_uart` 会每约 `300 ms` 主动上传一帧 28 字节状态包。上位机应持续接收并解析该状态包，用它更新界面中的实际状态。

状态包前 16 字节与基础帧格式一致，后 12 字节为扩展字段。

| 字节位置 | 字段 | 类型 | 字节序 | 单位/含义 |
|---|---|---|---|---|
| 0-1 | `header` | uint16 | 小端 | 固定 `0xFEFF` |
| 2 | `EmerStop` | uint8 | - | 当前急停状态，非 0 表示急停/关断状态 |
| 3 | `VolRelay` | uint8 | - | 继电器和风扇实际开关位 |
| 4-5 | `VolOutValue` | uint16 | 小端 | 当前保存的电压/预留设定值 |
| 6 | `HeFLOWRelay` | uint8 | - | He_MFC、氦气阀、蜂鸣器实际状态位 |
| 7-8 | `HeOutValue` | uint16 | 小端 | He_MFC 当前目标流量，单位 `0.01 L/min` |
| 9 | `ArFLOWRelay` | uint8 | - | Ar_MFC、氩气阀、RGB 状态位 |
| 10-11 | `ArOutValue` | uint16 | 小端 | Ar_MFC 当前目标流量，单位 `0.01 L/min` |
| 12-15 | `footer` | uint32 | 小端 | 前 12 字节逐字节求和 |
| 16-19 | `PlasmaFeedbackVpp` | float32 | 小端 | 等离子反馈 Vpp，单位 V |
| 20-23 | `HePressureValue` | float32 | 小端 | 氦气压力，单位 MPa；无效时为 `0.0` |
| 24-27 | `ArPressureValue` | float32 | 小端 | 氩气压力，单位 MPa；无效时为 `0.0` |

状态包校验只覆盖前 12 字节，和控制帧一致；扩展字段目前不参与校验。

## 9. 状态位解析

状态包中的 `VolRelay`、`HeFLOWRelay`、`ArFLOWRelay` 使用与普通控制命令相同的位定义，但代表下位机当前实际状态。

上位机界面建议：

- 继电器、气阀、风扇、蜂鸣器、RGB 的开关显示，应以状态包位为准；
- MFC 目标流量显示，应以状态包 `HeOutValue/ArOutValue` 为准；
- 等离子反馈 Vpp、压力值，应解析扩展 float32 字段；
- 命令发出后不要立即假定执行成功，应等待下一帧或几帧状态包确认。

RGB 位当前主要反映系统状态灯：

```text
硬件急停：红灯快速闪烁
cmd_uart 已握手：绿灯常亮
cmd_uart 未握手：黄灯慢速闪烁
```

所以 RGB 命令位只建议用于协议测试，不建议上位机把它作为自由颜色控制。

板载 LED1/LED2/LED3 也用于连接和急停状态指示：

```text
硬件急停或命令急停：LED1/LED2/LED3 同步闪烁
cmd_uart 已握手：LED1 常亮，LED2/LED3 熄灭
cmd_uart 未握手：LED1 -> LED2 -> LED3 跑马灯
```

## 10. 硬件急停行为

硬件急停输入为 INT3 / PE13，接常闭急停。正常闭合时为低电平；急停按下开路后变为高电平并触发硬件急停策略。

硬件急停触发后：

- `buzzer_1` 红色错误蜂鸣器响 5 个单次；
- 三色灯红灯快速闪烁；
- LED1/LED2/LED3 同步闪烁；
- `he_valve`、`ar_valve` 关闭；
- He_MFC、Ar_MFC 目标流量设为 `0.00 L/min`；
- `vol_mod_relay`、`plasma_relay` 关闭；
- `buzzer_2` 关闭；
- ADC 采样继续运行；
- 压力传感器通讯继续运行；
- USART1 日志继续输出；
- USART6 状态包继续上传。

硬件急停恢复后：

- 红色蜂鸣器停止；
- 黄色蜂鸣器响 2 个单次；
- 三色灯回到绿色常亮或黄色慢闪，由 `cmd_uart` 是否已握手决定；
- LED1/LED2/LED3 回到 `cmd_uart` 连接状态指示；
- 被关闭的电磁阀、继电器不会自动重新打开；
- MFC 目标流量保持 `0.00 L/min`，需要操作者重新设置。

硬件急停按下期间，下位机仍接收串口数据，但控制命令不会落到执行器。

## 11. 上位机解析建议

### 11.1 接收状态包

串口接收建议使用滑动缓冲区：

1. 不断读入串口字节；
2. 查找包头字节序列 `FF FE`；
3. 如果缓冲区不足 16 字节，继续等待；
4. 对前 16 字节按基础帧校验；
5. 如果需要解析完整状态包，继续等待到 28 字节；
6. 前 16 字节校验正确后，解析 16-27 字节扩展字段；
7. 如果校验失败，丢弃当前包头第一个字节，继续查找下一个包头。

### 11.2 发送控制命令

上位机每次发送命令时建议完整构造 16 字节包：

1. 写入固定包头 `FF FE`；
2. 写入控制字段；
3. 对前 12 字节求和；
4. 写入 4 字节小端校验；
5. 发送；
6. 等待状态包确认。

不要只发送变化字段；下位机每次收到普通控制帧会按当前帧的字段整体刷新相关执行器。

### 11.3 发送频率

当前下位机没有对上位机命令做队列。建议：

- 普通控制命令不要高频连续发送；
- 人机界面按钮类命令，按操作发送即可；
- 滑块类命令建议限速，例如 `100-200 ms` 发送一次；
- 风扇调速和 MFC 流量设定发送后，以状态包回读值确认。

## 12. 常用命令示例

### 12.1 `cmd_uart` 握手

发送：

```text
FF FE C5 A5 A5 5A 3C 3C C3 96 96 69 36 07 00 00
```

期望 ACK：

```text
FF FE CA A5 A5 5A 3C 3C C3 96 96 69 3B 07 00 00
```

### 12.2 打开等离子电源继电器

```text
FF FE 00 10 00 00 00 00 00 00 00 00 0D 02 00 00
```

### 12.3 打开调压器继电器

```text
FF FE 00 01 00 00 00 00 00 00 00 00 FE 01 00 00
```

### 12.4 He_MFC 上电并设为 1.00 L/min，同时打开氦气电磁阀

```text
FF FE 00 00 00 00 11 64 00 00 00 00 72 02 00 00
```

### 12.5 He_MFC 上电并设为 5.00 L/min，同时打开氦气电磁阀

```text
FF FE 00 00 00 00 11 F4 01 00 00 00 03 03 00 00
```

### 12.6 只打开氩气电磁阀

```text
FF FE 00 00 00 00 00 00 00 01 00 00 FE 01 00 00
```

### 12.7 三路风扇分别设置为 30%、60%、90%

```text
FF FE A5 E0 2C 01 00 58 02 00 84 03 90 04 00 00
```

### 12.8 急停测试组合命令

除三色灯和蜂鸣器外，继电器、气阀、MFC 供电位和三路风扇全部打开，并把 He/Ar MFC 目标流量设为 1.00 L/min：

```text
FF FE 00 F1 00 00 11 64 00 11 64 00 D8 03 00 00
```

### 12.9 全部关闭

```text
FF FE 00 00 00 00 00 00 00 00 00 00 FD 01 00 00
```

### 12.10 命令急停

```text
FF FE F8 00 00 00 00 00 00 00 00 00 F5 02 00 00
```

## 13. Python 解析示例

```python
import struct

HEADER = b"\xFF\xFE"

def checksum12(data: bytes) -> int:
    return sum(data[:12]) & 0xFFFFFFFF

def build_packet(emer, vol_relay, vol_value, he_relay, he_value, ar_relay, ar_value):
    pkt = bytearray(16)
    pkt[0:2] = HEADER
    pkt[2] = emer & 0xFF
    pkt[3] = vol_relay & 0xFF
    pkt[4:6] = struct.pack("<H", vol_value & 0xFFFF)
    pkt[6] = he_relay & 0xFF
    pkt[7:9] = struct.pack("<H", he_value & 0xFFFF)
    pkt[9] = ar_relay & 0xFF
    pkt[10:12] = struct.pack("<H", ar_value & 0xFFFF)
    pkt[12:16] = struct.pack("<I", checksum12(pkt))
    return bytes(pkt)

def parse_state_packet(pkt: bytes):
    if len(pkt) < 28:
        raise ValueError("state packet needs 28 bytes")
    if pkt[0:2] != HEADER:
        raise ValueError("bad header")
    recv_sum = struct.unpack_from("<I", pkt, 12)[0]
    calc_sum = checksum12(pkt)
    if recv_sum != calc_sum:
        raise ValueError(f"bad checksum recv={recv_sum:#x} calc={calc_sum:#x}")

    state = {
        "emer_stop": pkt[2],
        "vol_relay": pkt[3],
        "vol_out_value": struct.unpack_from("<H", pkt, 4)[0],
        "he_flow_relay": pkt[6],
        "he_target_lpm": struct.unpack_from("<H", pkt, 7)[0] / 100.0,
        "ar_flow_relay": pkt[9],
        "ar_target_lpm": struct.unpack_from("<H", pkt, 10)[0] / 100.0,
        "plasma_vpp_v": struct.unpack_from("<f", pkt, 16)[0],
        "he_pressure_mpa": struct.unpack_from("<f", pkt, 20)[0],
        "ar_pressure_mpa": struct.unpack_from("<f", pkt, 24)[0],
    }
    return state

# He_MFC 1.00 L/min + he_valve ON
cmd = build_packet(
    emer=0x00,
    vol_relay=0x00,
    vol_value=0,
    he_relay=0x11,
    he_value=100,
    ar_relay=0x00,
    ar_value=0,
)
print(cmd.hex(" ").upper())
```

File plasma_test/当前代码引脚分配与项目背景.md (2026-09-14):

# 等离子设备控制板当前代码引脚分配说明

> 本文档结合 `板子资源.md`、`项目背景.md` 以及当前 `plasma_test` 工程代码整理。  
> 目标是记录当前固件已经实际接入的板卡资源、业务含义、控制协议和安全默认状态，方便后续继续开发、接线核对和上位机联调。

## 1. 项目背景

本项目面向一套等离子设备控制系统。设备以氦气或氩气作为工作气体，在受控气体流量和受控供电条件下产生稳定的等离子体。

控制板当前承担的核心职责包括：

- 管理氦气、氩气两路气体通路；
- 控制两路 MFC/流量控制器的供电通断；
- 控制两路气体电磁阀的开启和关闭；
- 控制调压器继电器和等离子电源继电器；
- 读取调压器初始位置、最大位置两个限位开关；
- 通过 USART1/CH340 接收调试命令，并输出操作者可读状态日志；
- 通过 USART6/485-2 接收上位机命令，并回传 28 字节二进制状态包。

设备典型业务链路为：

```text
气源检查 -> MFC 上电 -> 气体电磁阀打开 -> 流量建立
-> 调压器调整 -> 等离子电源启动 -> 运行状态监控
```

当前代码还处于底层资源接入和联调阶段，已经完成继电器、气阀、限位输入、串口命令和状态日志的基础框架。

## 2. 当前固件工程

| 项目 | 当前配置 |
|---|---|
| 工程目录 | `plasma_test` |
| MCU | STM32F407VGT6 |
| 开发框架 | STM32CubeMX + HAL |
| Keil 工程 | `plasma_test/MDK-ARM/plasma_test.uvprojx` |
| 主程序 | `plasma_test/Src/main.c` |
| 调试/日志串口 | USART1 / CH340 |
| 上位机命令串口 | USART6 / 485-2 / J365 |
| 串口参数 | 115200, 8N1 |
| 接收命令格式 | 16 字节二进制包 |
| USART1 回传内容 | ASCII 状态日志，每约 1000 ms 一次 |
| USART6 回传内容 | 28 字节二进制状态包，每约 300 ms 一次 |
| 上位机协议文档 | `上位机通讯协议说明.md` |

## 3. 当前已分配引脚总表

| 功能 | 代码别名 | 板子网络/接口 | MCU 引脚 | 方向 | 有效状态 | 当前代码文件 |
|---|---|---|---|---|---|---|
| USART1_TX | `log_uart` | CH340 串口 TX 通道 | PA9 | 输出 | USART1 AF7 | `Src/usart.c` |
| USART1_RX | `log_uart` | CH340 串口 RX 通道 | PA10 | 输入 | USART1 AF7 | `Src/usart.c` |
| 氦气压力 RS485_TX | `he_pressure_uart` | 485-3 / J367 | PA2 | 输出 | USART2 AF7 | `Src/usart.c`, `gas_pressure.c` |
| 氦气压力 RS485_RX | `he_pressure_uart` | 485-3 / J367 | PA3 | 输入 | USART2 AF7 | `Src/usart.c`, `gas_pressure.c` |
| 氩气压力 RS485_TX | `ar_pressure_uart` | 485-1 / J366 | PA0 | 输出 | UART4 AF8 | `Src/usart.c`, `gas_pressure.c` |
| 氩气压力 RS485_RX | `ar_pressure_uart` | 485-1 / J366 | PA1 | 输入 | UART4 AF8 | `Src/usart.c`, `gas_pressure.c` |
| USART6_TX | `cmd_uart` | 485-2 / `485_A_2`、`485_B_2` | PC6 | 输出 | USART6 AF8 | `Src/usart.c` |
| USART6_RX | `cmd_uart` | 485-2 / `485_A_2`、`485_B_2` | PC7 | 输入 | USART6 AF8 | `Src/usart.c` |
| LED1 | `LED1` | D71 | PD3 | 输出 | 低电平亮；当前用于 `cmd_uart` 连接/急停状态指示 | `Inc/main.h`, `packet_comm.c` |
| LED2 | `LED2` | D72 | PD4 | 输出 | 低电平亮；当前用于 `cmd_uart` 连接/急停状态指示 | `Inc/main.h`, `packet_comm.c` |
| LED3 | `LED3` | D73 | PD7 | 输出 | 低电平亮；当前用于 `cmd_uart` 连接/急停状态指示 | `Inc/main.h`, `packet_comm.c` |
| He_MFC 电源继电器 | `He_MFC` / `HE_MFC_PWR_EN` | SWRAY2 | PC3 | 输出 | 高电平上电，当前有效 | `mfc.c` |
| Ar_MFC 电源继电器 | `Ar_MFC` / `AR_MFC_PWR_EN` | SWRAY1 | PC2 | 输出 | 高电平上电，当前禁用 | `mfc.c` |
| 调压器继电器 | `vol_mod_relay` | SWRAY3 | PC1 | 输出 | 高电平开 | `bsp_relay.c` |
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

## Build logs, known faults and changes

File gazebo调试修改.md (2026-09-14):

# Gazebo 调试修改记录

针对 `ros2 launch rm_bringup rm_eco65_gazebo.launch.py` 命令的调试修改汇总。

---

## 1. `use_sim_time` 参数不一致

**文件**：`src/plasma_robot/rm_moveit2_config/rm_eco65_config/launch/gazebo_moveit_demo.launch.py`

**问题**：`move_group` 和 `rviz2` 节点未设置 `use_sim_time`，默认为 `False`；而 `robot_state_publisher` 设置了 `use_sim_time: True`。时间不一致导致 `move_group` 认为 `/joint_states` 时间戳过期（超过 1 秒），拒绝执行轨迹。

**原来**：`move_group` 和 `rviz2` 的 `parameters` 列表中没有 `use_sim_time` 条目。

**改为**：
```python
# move_group
{"use_sim_time": True}

# rviz2
{"use_sim_time": True}
```

同时放宽轨迹执行超时参数（防止 sim time 偏差导致提前中止）：
```python
trajectory_execution = {
    "moveit_manage_controllers": True,
    "trajectory_execution.allowed_execution_duration_scaling": 5.0,
    "trajectory_execution.allowed_goal_duration_margin": 5.0,
    "trajectory_execution.allowed_start_tolerance": 0.0,
}
```

---

## 2. `gzserver` 崩溃（Segmentation fault）/ Gazebo 窗口卡死

**文件**：`src/plasma_robot/rm_gazebo/config/gazebo_eco65_description.urdf.xacro`

**问题**：URDF 中同时存在 `<is_static>true</is_static>` 和 `gazebo_ros2_control` 插件。`is_static=true` 让 Gazebo 物理引擎冻结所有关节，而 `gazebo_ros2_control` 需要驱动这些关节，二者直接冲突，导致 gzserver 在加载插件时 Segmentation fault（exit code 139）。

> 注意：`is_static` 最终被保留，因为去掉后关节在某些姿态下因重力问题到不了目标位姿（见第 5 条修复前的临时状态）。

---

## 3. Gazebo 窗口黑屏

**文件**：`src/plasma_robot/rm_gazebo/launch/gazebo_eco65_demo.launch.py`

**问题**：`GAZEBO_MODEL_PATH` 未设置，gzclient 尝试从 `fuel.gazebosim.org` 下载 `ground_plane` 和 `sun` 模型，网络不通导致黑屏。本机 `/usr/share/gazebo-11/models/` 下已有这两个模型。

**原来**：launch 文件中没有设置 `GAZEBO_MODEL_PATH`。

**改为**：在 launch 文件中添加：
```python
from launch.actions import SetEnvironmentVariable

set_gazebo_model_path = SetEnvironmentVariable(
    name='GAZEBO_MODEL_PATH',
    value='/usr/share/gazebo-11/models:' + os.environ.get('GAZEBO_MODEL_PATH', '')
)
```

---

## 4. 重复启动 `robot_state_publisher` 导致 invalid sequence

**文件**：`src/plasma_robot/rm_moveit2_config/rm_eco65_config/launch/gazebo_moveit_demo.launch.py`

**问题**：`gazebo_eco65_demo.launch.py` 已经启动了一个带 `use_sim_time: True` 的 `robot_state_publisher`（节点编号 `-3`），`gazebo_moveit_demo.launch.py` 又启动了第二个不带 `use_sim_time` 的同名节点（编号 `-9`）。两个节点同时发布 `robot_description`，导致 `gazebo_ros2_control` 收到 "invalid sequence number"，进而触发 gzserver segfault，controller_manager 消失。

**原来**：
```python
robot_state_publisher = Node(
    package="robot_state_publisher",
    executable="robot_state_publisher",
    name="robot_state_publisher",
    output="both",
    parameters=[robot_description],
)
# LaunchDescription 中包含 robot_state_publisher
```

**改为**：注释掉该节点，并从 `LaunchDescription` 中移除：
```python
# NOTE: robot_state_publisher is already started by gazebo_eco65_demo.launch.py
# robot_state_publisher = Node(...)
```

---

## 5. `<gazebo reference>` link 名大小写错误

**文件**：`src/plasma_robot/rm_gazebo/config/gazebo_eco65_description.urdf.xacro`

**问题**：URDF 中 link 名为 `Link1`~`Link6`（首字母大写），但 `<gazebo reference>` 标签中写的是 `link1`~`link6`（全小写），Gazebo 找不到对应 link，导致：
- `<gravity>false</gravity>` 未生效 → 重力持续作用 → 机械臂缓慢下坠
- `<material>Gazebo/xxx</material>` 未生效 → Gazebo 中看不到颜色
- 下垂导致下次运动起始位置错误 → 到不了目标位姿

**原来**：
```xml
<gazebo reference="link1">...</gazebo>
<gazebo reference="link2">...</gazebo>
...（link3~link6 同理）
```

**改为**：
```xml
<gazebo reference="Link1">...</gazebo>
<gazebo reference="Link2">...</gazebo>
...（Link3~Link6 同理）
```

---

## 6. `static_transform_publisher` 的 child frame 名写错

**文件**：`src/plasma_robot/rm_moveit2_config/rm_eco65_config/launch/gazebo_moveit_demo.launch.py`

**问题**：所有 URDF 和 SRDF 中根 link 名均为 `baselink`（无下划线），但 `static_transform_publisher` 发布的 TF 是 `world → base_link`（有下划线），导致 TF 树中多了一个孤立的 `base_link` frame，MoveIt 规划坐标系偏移，执行后位姿差一点。

**原来**：
```python
arguments=["0.0", "0.0", "0.0", "0.0", "0.0", "0.0", "world", "base_link"],
```

**改为**：
```python
arguments=["0.0", "0.0", "0.0", "0.0", "0.0", "0.0", "world", "baselink"],
```

---

## 遗留问题

**`rm_eco65_gazebo.urdf` 与 `rm_eco65.urdf` 关节限位不一致**：两个文件中 joint1~joint6 的 `lower`/`upper` 值不同，Gazebo 执行时会将超出自身 limit 的目标角度夹在边界，导致位姿偏差。需确认哪份数据为准后统一。

| 关节 | `rm_eco65_gazebo.urdf` (Gazebo) | `rm_eco65.urdf` (MoveIt) |
|---|---|---|
| joint1 | -3.1923 ~ 3.1923 | -3.1067 ~ 3.1067 |
| joint2 | -2.61666 ~ 2.442 | -3.1067 ~ 2.3562 |
| joint3 | -2.61666 ~ 2.61666 | -2.7925 ~ 2.5307 |
| joint4 | -2.61666 ~ 2.61666 | -3.1067 ~ 3.1067 |
| joint5 | -2.96555 ~ 2.96555 | -3.1067 ~ 3.1067 |
| joint6 | 待确认 | -6.2832 ~ 6.2832 |

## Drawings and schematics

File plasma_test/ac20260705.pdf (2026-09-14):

GND_IN | GND

# 12V_IN

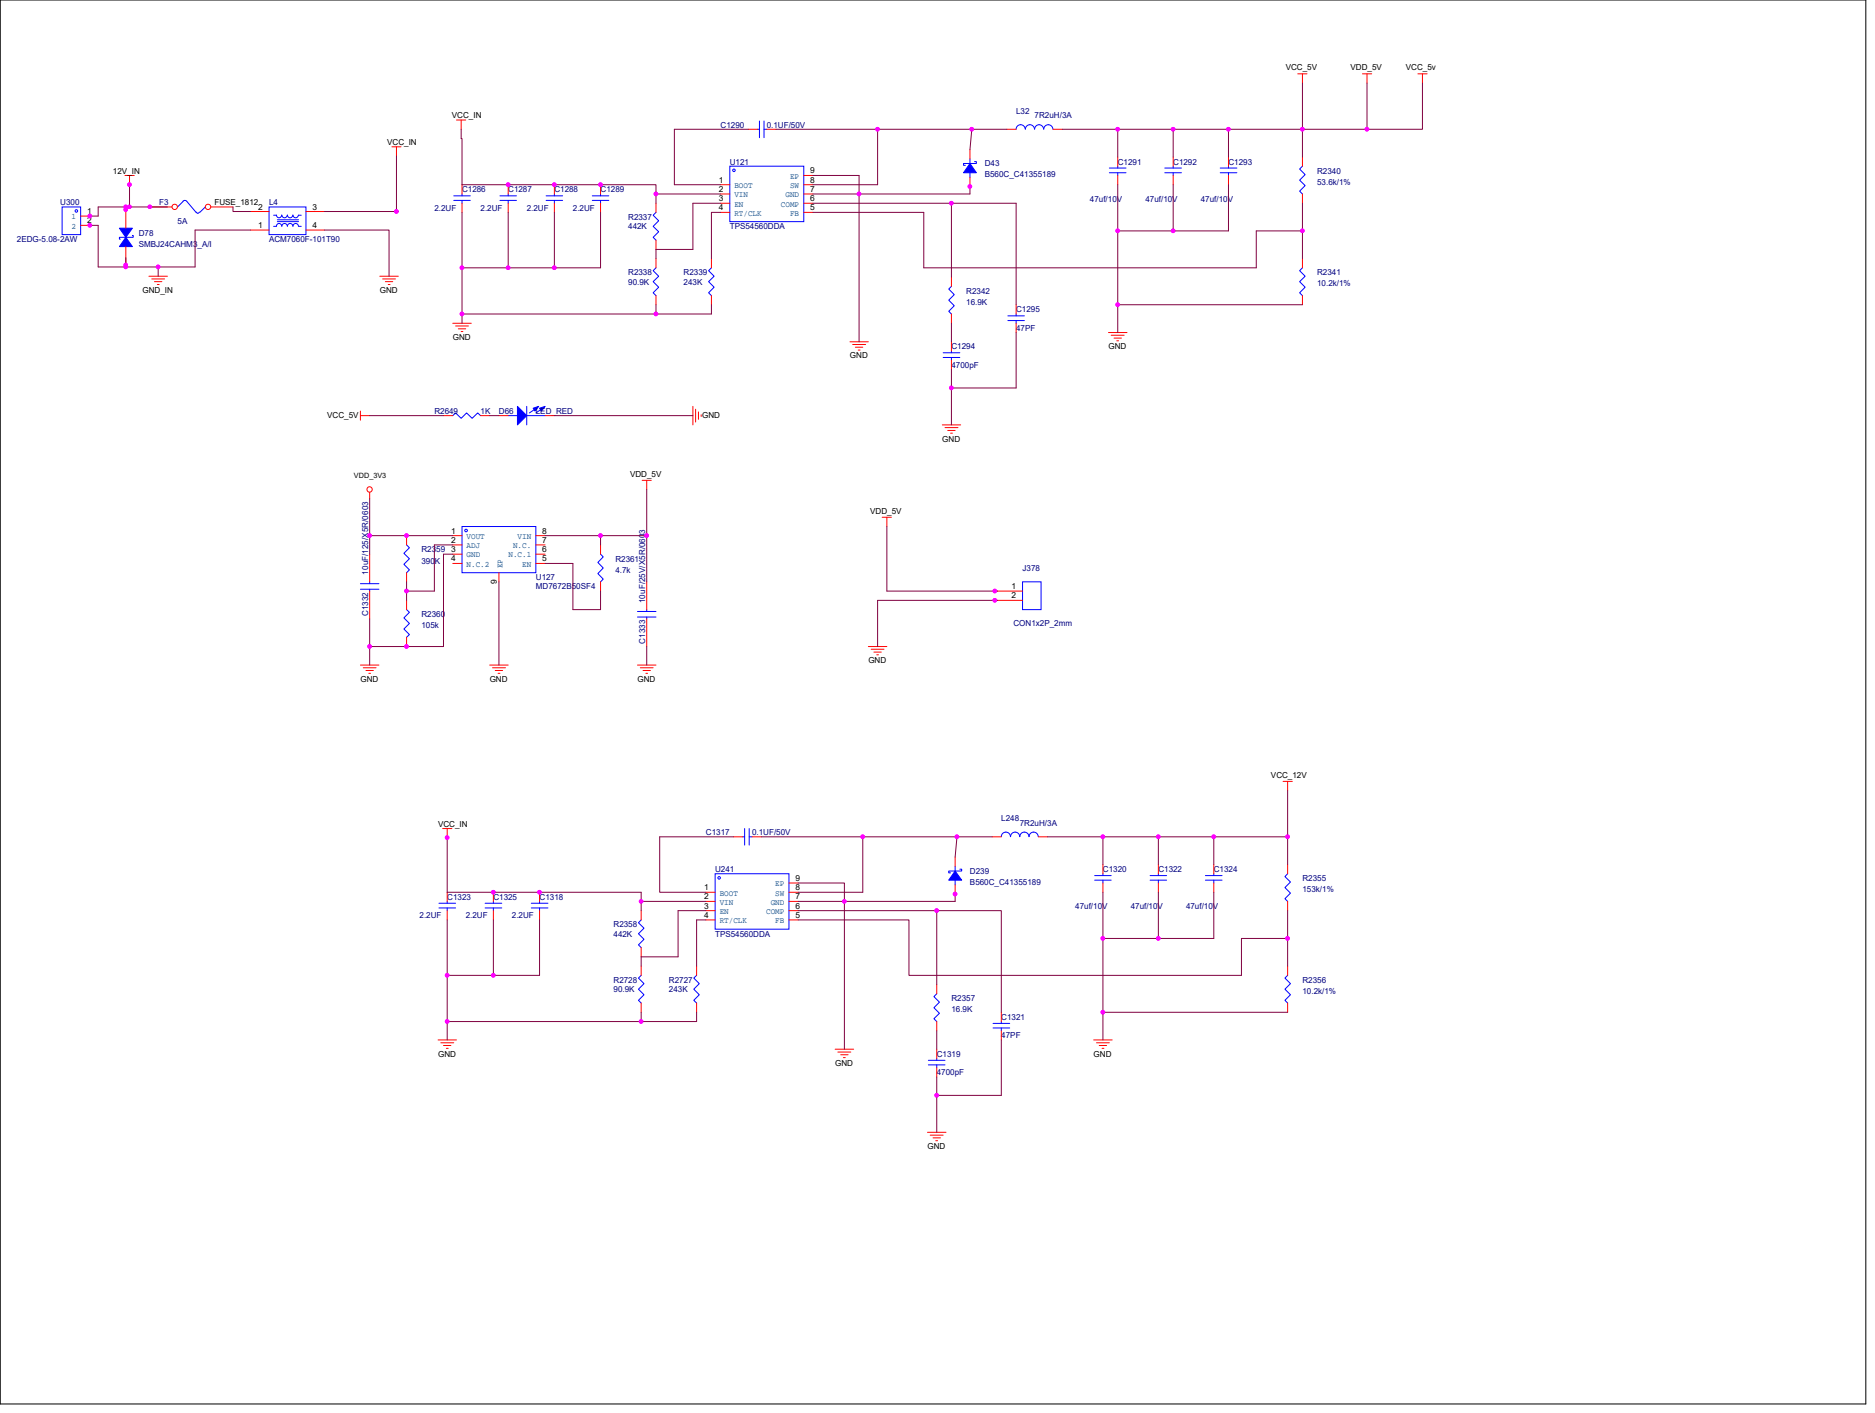
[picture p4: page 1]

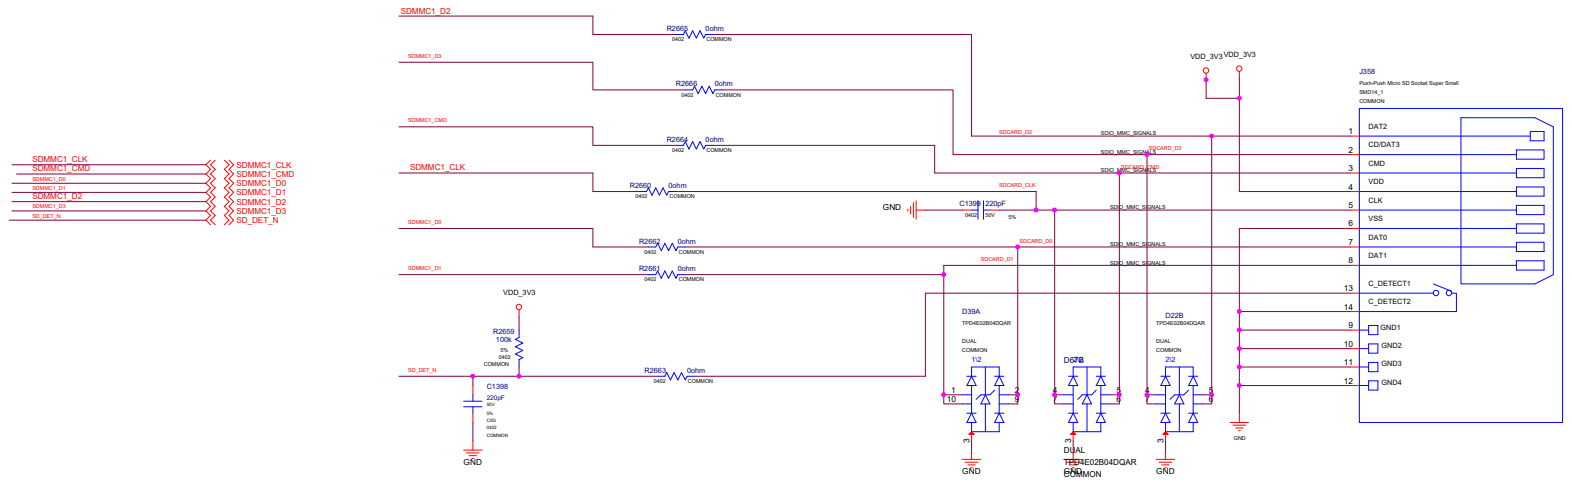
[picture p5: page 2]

Push-Push Micro SD Socket Super Small
SMD14_1
COMMON

# 5.08 220V输输

# ADC步压电电

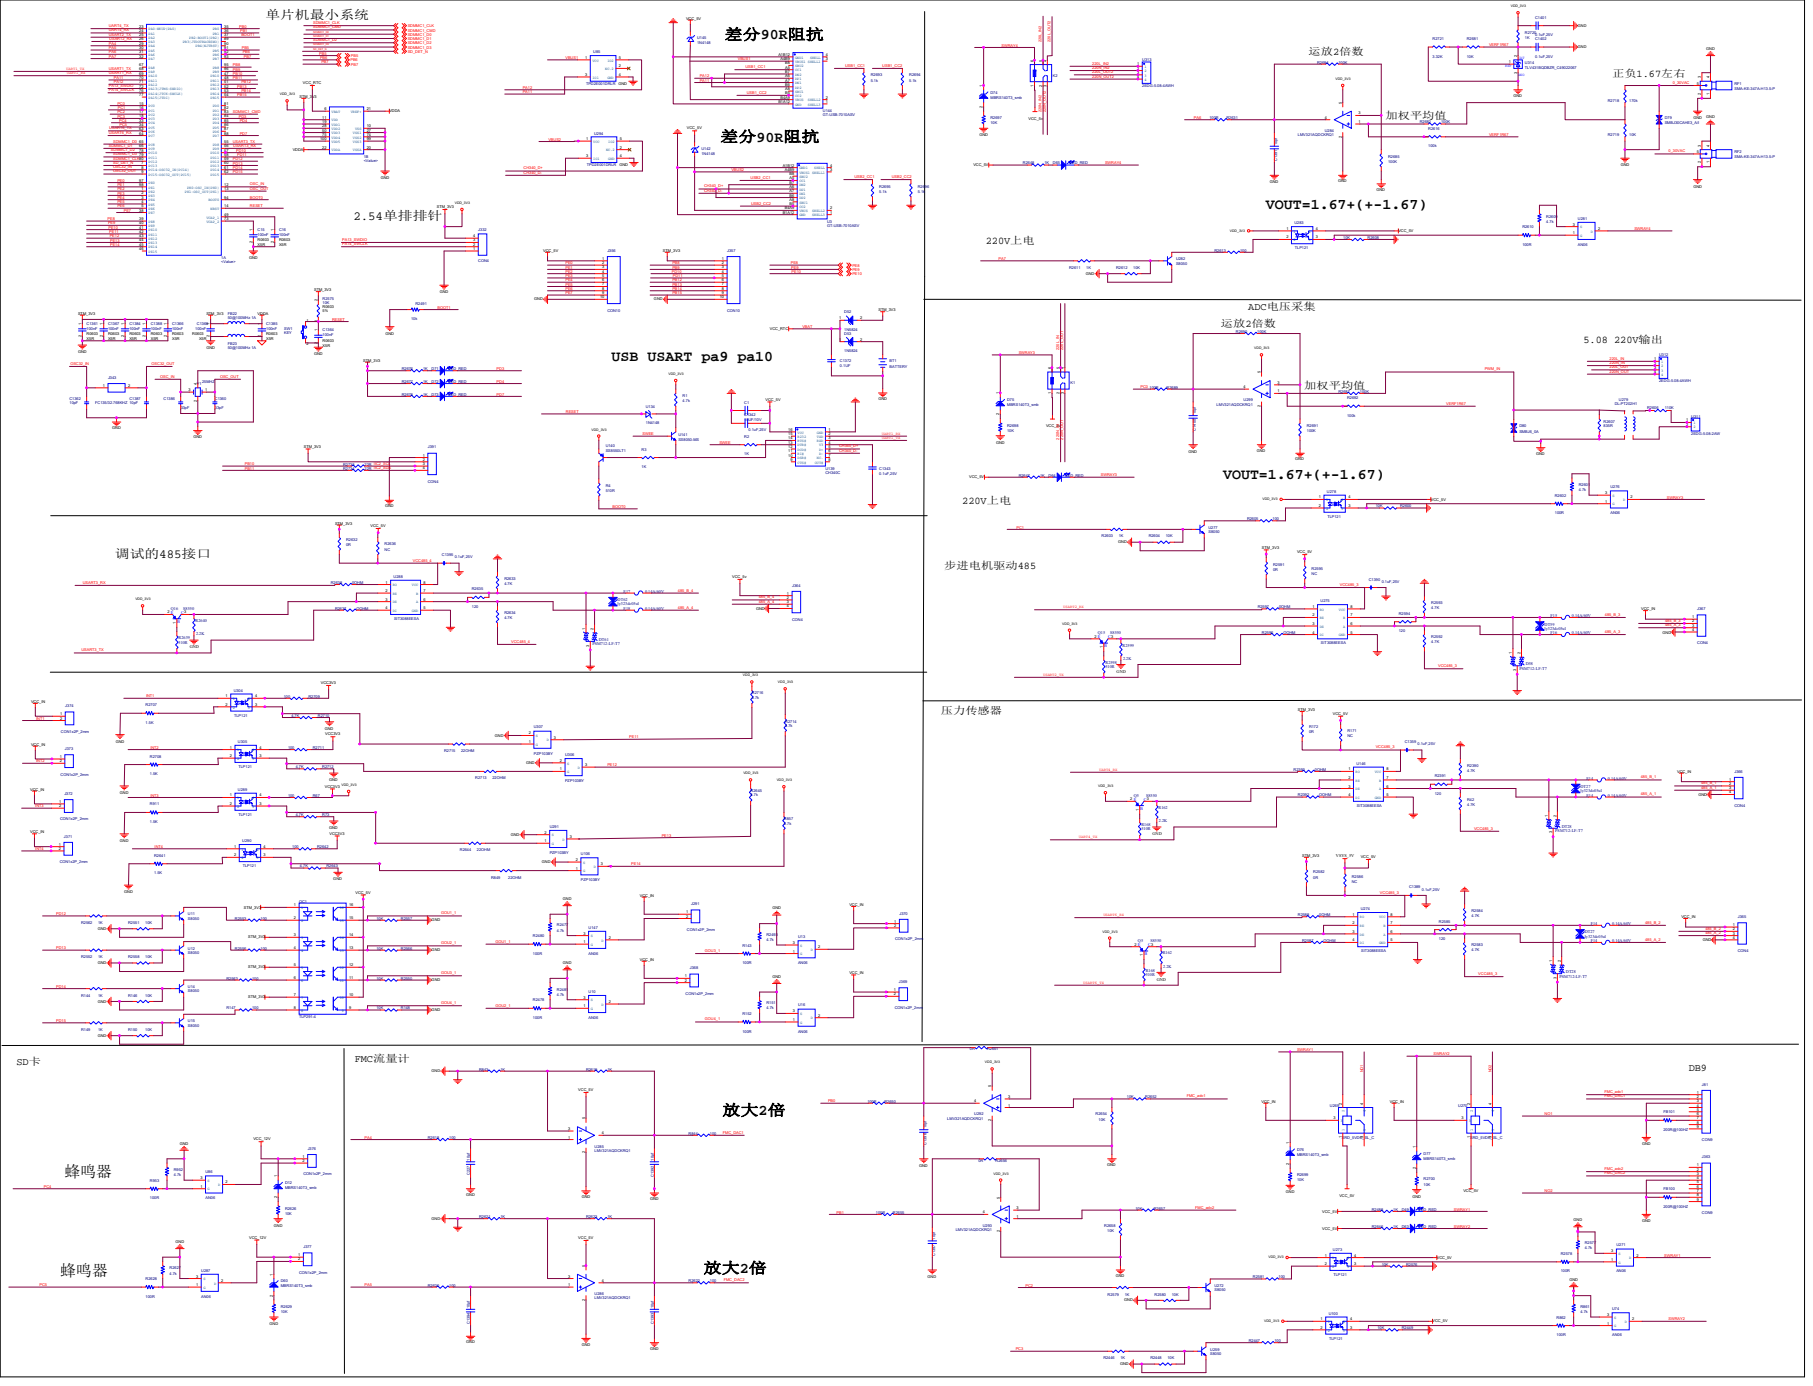
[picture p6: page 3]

4.7K R2643 GND VCC_5V GND | S 2 G 1 | VCC_IN | R2586 NC

SD 卡 GND VCC_12V 100R 100R | FMC流流流 | SWRAY1 DB9

# FAN

# FAN

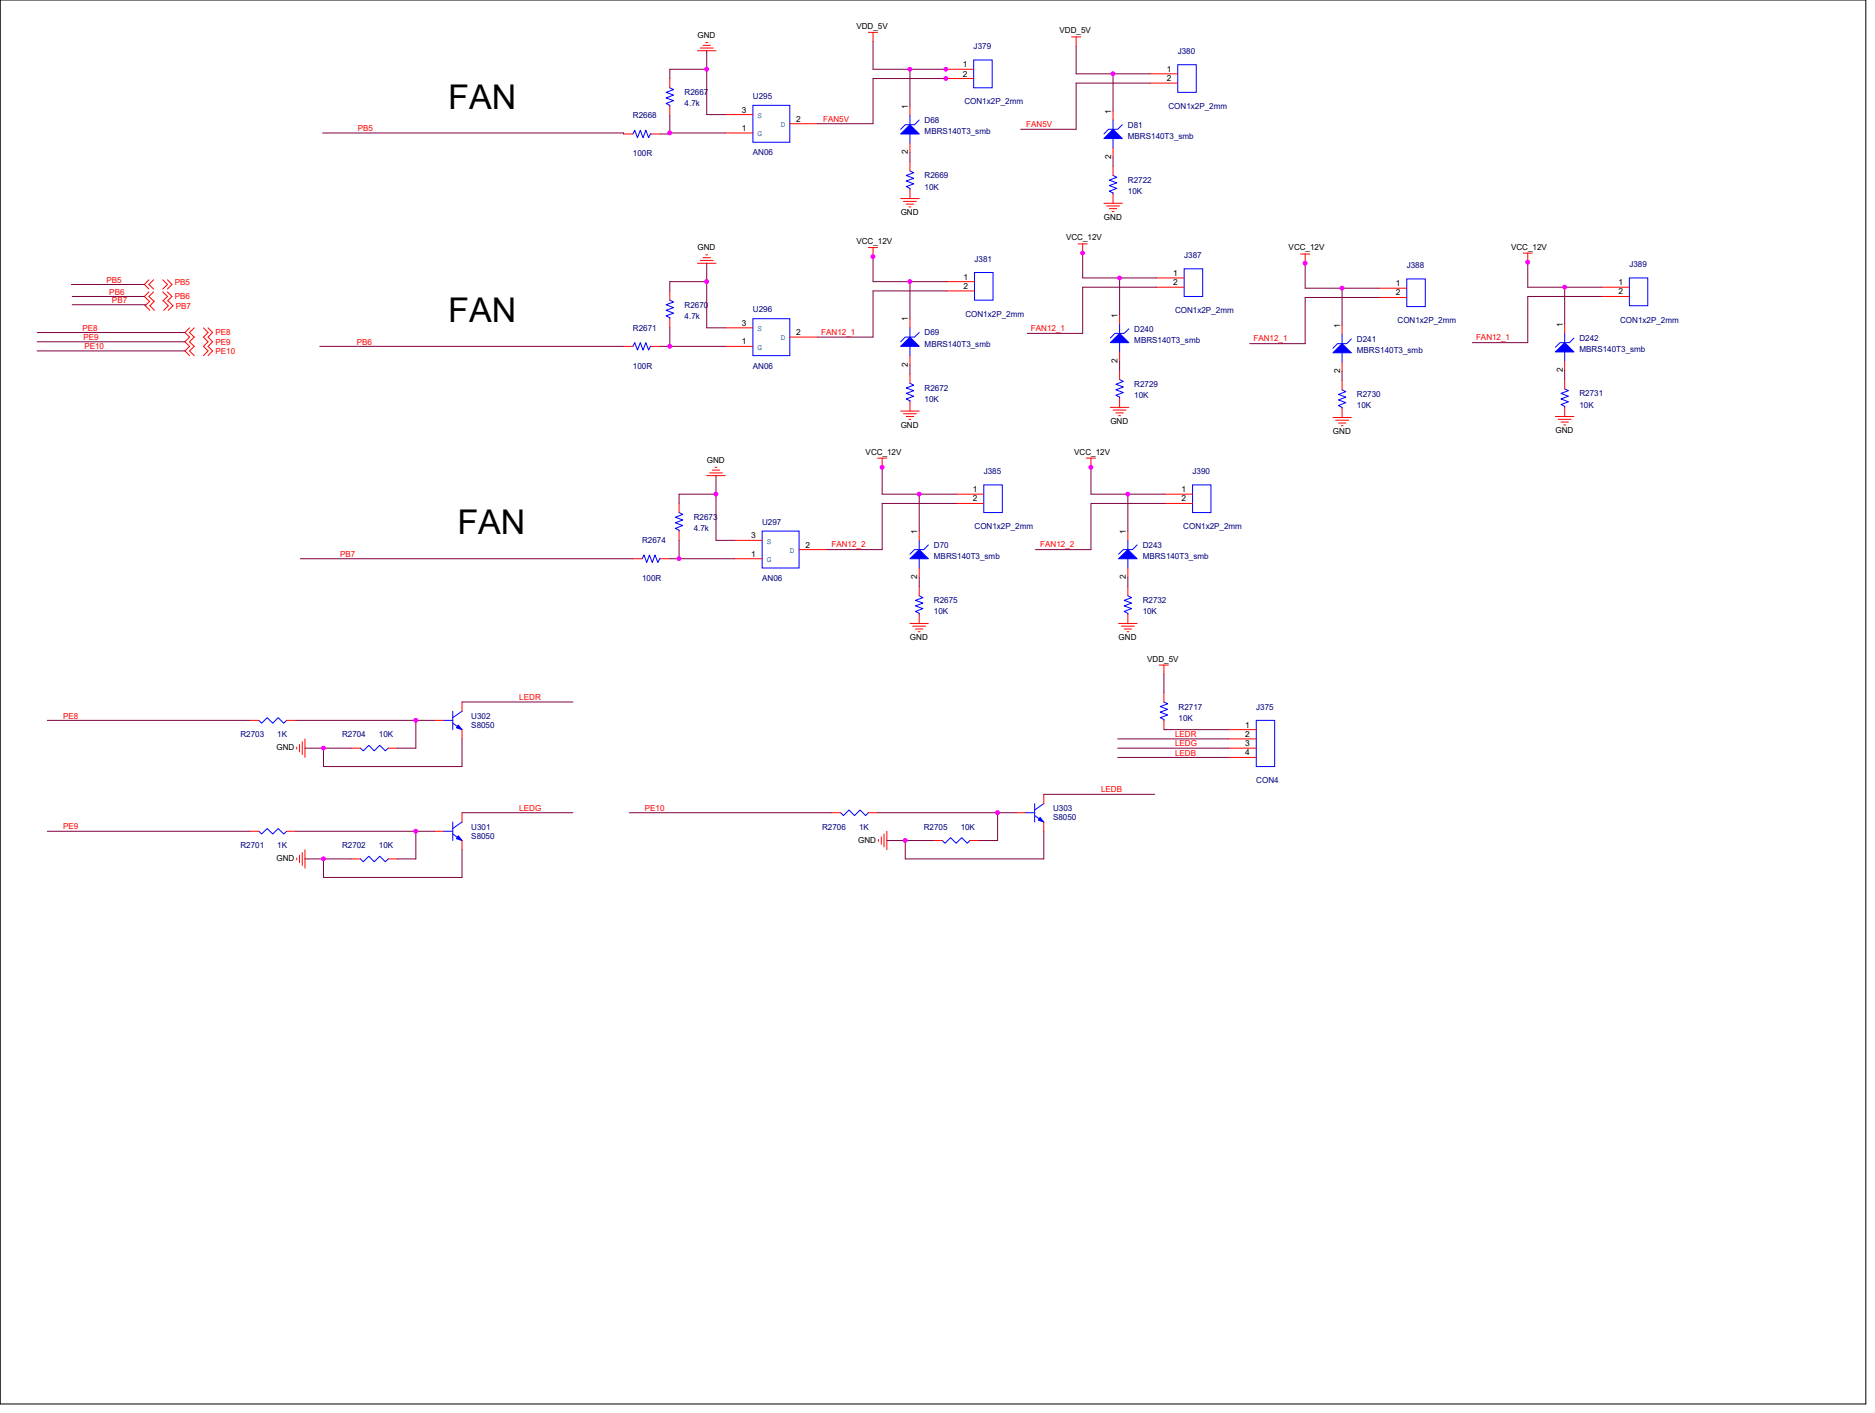
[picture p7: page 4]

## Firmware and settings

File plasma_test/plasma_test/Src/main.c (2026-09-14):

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
/* Includes ------------------------------------------------------------------*/
#include "main.h"
#include "usart.h"
#include "gpio.h"

/* USER CODE BEGIN Includes */
#include "bsp_buzzer.h"
#include "bsp_fan.h"
#include "bsp_gas_valve.h"
#include "bsp_limit_switch.h"
#include "bsp_plasma_feedback.h"
#include "bsp_relay.h"
#include "bsp_rgb.h"
#include "gas_pressure.h"
#include "mfc.h"
#include "packet_comm.h"

/* USER CODE END Includes */

/* USER CODE BEGIN PD */
#define LED_OFF       GPIO_PIN_SET

/* USER CODE END PD */


/* USER CODE BEGIN PV */
static uint32_t lastPacketSendTick = 0U;
static uint32_t lastCmdPacketSendTick = 0U;

/* USER CODE END PV */

void SystemClock_Config(void);
/* USER CODE BEGIN PFP */
static void LED_AllOff(void);

/* USER CODE END PFP */

/**
  * @brief  The application entry point.
  * @retval int
  */
int main(void)
{

  /* MCU Configuration--------------------------------------------------------*/

  /* Reset of all peripherals, Initializes the Flash interface and the Systick. */
  HAL_Init();

  /* Configure the system clock */
  SystemClock_Config();

  /* Initialize all configured peripherals */
  MX_GPIO_Init();
  MX_USART1_UART_Init();
  /* USER CODE BEGIN 2 */
  MX_USART2_UART_Init();
  MX_UART4_UART_Init();
  MX_USART6_UART_Init();
  LED_AllOff();
  BoardRelay_Init();
  BoardGasValve_Init();
  BoardLimitSwitch_Init();
  BoardFan_Init();
  BoardBuzzer_Init();
  BoardRgb_Init();
  (void)MFC_Init();
  (void)PlasmaFeedback_Init();
  (void)PlasmaFeedback_Start();
  GasPressure_Init();
  PacketComm_Init(&log_uart, &cmd_uart);
  lastPacketSendTick = HAL_GetTick();
  lastCmdPacketSendTick = HAL_GetTick();

  /* USER CODE END 2 */

  /* Infinite loop */
  /* USER CODE BEGIN WHILE */
  while (1)
  {
    /* USER CODE END WHILE */

    /* USER CODE BEGIN 3 */
    if (PacketComm_Process(PACKET_COMM_PORT_LOG) == PACKET_COMM_OK)
    {
      PacketComm_ApplyReceivedPacket();
    }

    if (PacketComm_Process(PACKET_COMM_PORT_HOST) == PACKET_COMM_OK)
    {
      PacketComm_ApplyReceivedPacket();
    }

    PacketComm_ProcessHardwareEmergency();
    PacketComm_ProcessConnectionIndicator();
    BoardBuzzer_Process();
    (void)PlasmaFeedback_Process();
    GasPressure_Process();

    if ((HAL_GetTick() - lastCmdPacketSendTick) >= PACKET_COMM_CMD_SEND_MS)
    {
      (void)PacketComm_SendStatePacket(PACKET_COMM_PORT_HOST);
      lastCmdPacketSendTick = HAL_GetTick();
    }

    if ((HAL_GetTick() - lastPacketSendTick) >= PACKET_COMM_SEND_MS)
    {
      (void)PacketComm_SendStatus();
      lastPacketSendTick = HAL_GetTick();
    }
  }
  /* USER CODE END 3 */
}

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
/* USER CODE BEGIN 4 */
static void LED_AllOff(void)
{
  HAL_GPIO_WritePin(LED1_GPIO_Port, LED1_Pin, LED_OFF);
  HAL_GPIO_WritePin(LED2_GPIO_Port, LED2_Pin, LED_OFF);
  HAL_GPIO_WritePin(LED3_GPIO_Port, LED3_Pin, LED_OFF);
}

/* USER CODE END 4 */
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


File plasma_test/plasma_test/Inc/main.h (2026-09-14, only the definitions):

#define LED1_Pin GPIO_PIN_3
#define LED1_GPIO_Port GPIOD
#define LED2_Pin GPIO_PIN_4
#define LED2_GPIO_Port GPIOD
#define LED3_Pin GPIO_PIN_7
#define LED3_GPIO_Port GPIOD

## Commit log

2026-04-16 初次提交
2026-09-14 chore: archive current PlasmaRobot project state for GitHub
    [pcd01.ply, pcd02-1.ply, pcd02.ply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]

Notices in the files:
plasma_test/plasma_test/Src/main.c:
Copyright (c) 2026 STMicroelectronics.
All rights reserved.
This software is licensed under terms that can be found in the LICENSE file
